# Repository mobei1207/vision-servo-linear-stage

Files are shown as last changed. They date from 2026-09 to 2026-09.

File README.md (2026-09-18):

# vision-servo-linear-stage

> 基于 STM32F103C8T6 与 Python/OpenCV 的视觉伺服直线运动平台，DM542 驱动 57 步进电机，串口通信实现视觉闭环自动对准。

[]()
[]()
[]()
[]()

---

## 项目简介

本项目为机械电子工程专业综合设计，开发一套基于视觉伺服控制的直线运动平台。系统采用上下位机主从控制架构：

- **上位机**：PC + Python + OpenCV，通过 USB 工业相机采集图像，识别红色目标，计算目标质心与画面中心的像素偏差，经串口发送运动指令。
- **下位机**：STM32F103C8T6，接收串口指令，输出 PWM 脉冲与方向信号，控制 DM542 驱动 57 步进电机，经 7:1 减速器带动 ECB80D 同步带模组，实现 500mm 行程内的直线运动。
- **闭环逻辑**：视觉检测 → 偏差计算 → 串口指令 → 电机运动 → 平台移动 → 视觉再检测，形成视觉闭环自动对准。

---

## 系统架构

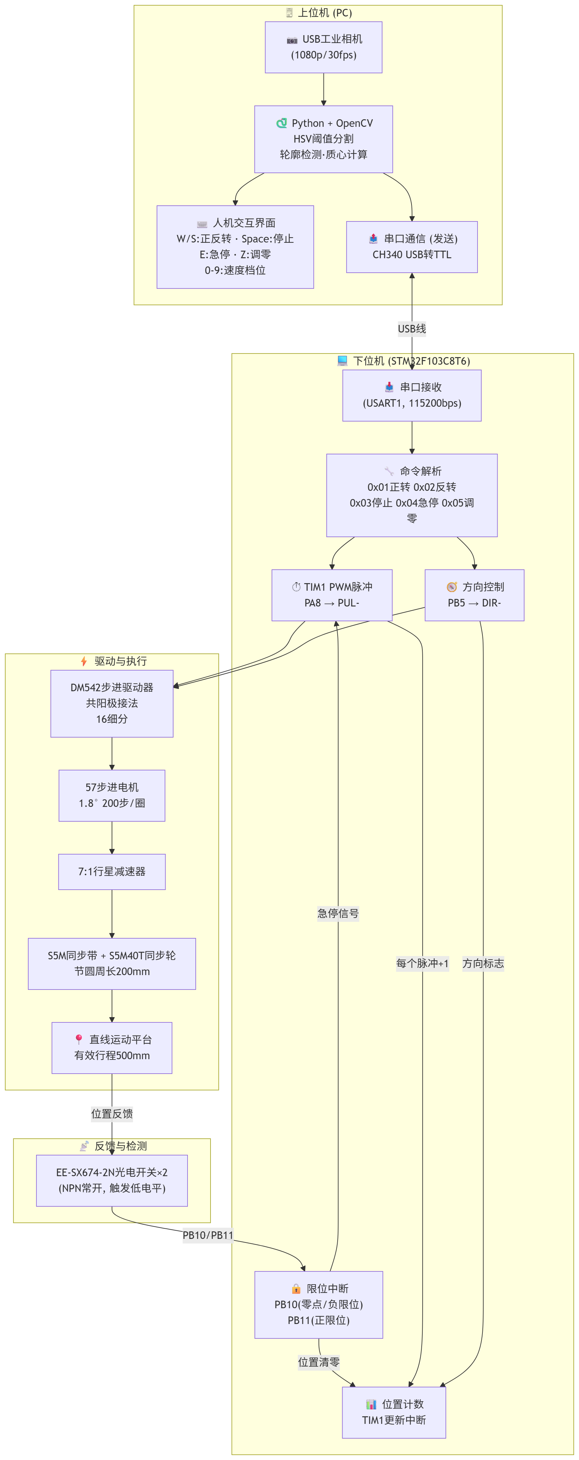
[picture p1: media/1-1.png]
系统结构图


---

## 硬件清单

| 类别 | 型号/规格 | 数量 | 说明 |
|---|---|---|---|
| 主控 | STM32F103C8T6 | 1 | 48 引脚 LQFP，72MHz |
| 驱动器 | DM542 | 1 | 两相步进驱动器，16 细分，共阳极接法 |
| 电机 | 57 两相混合式步进电机 | 1 | 机身 56mm，保持转矩约 1.2N·m，步距角 1.8° |
| 减速器 | 7:1 行星减速器 | 1 | 放大转矩，提高低速平稳性 |
| 模组 | ECB80D 欧规同步带模组 | 1 | 有效行程 500mm，重复定位精度 ±0.05mm |
| 同步轮 | S5M40T | 1 | 40 齿，节距 5mm，节圆周长 200mm |
| 同步带 | S5M 圆弧齿同步带 | 1 | 带宽 15mm |
| 相机 | USB 工业相机 | 1 | 1080p/30fps |
| 串口模块 | CH340 | 1 | USB 转 TTL，115200bps |
| 限位开关 | EE-SX674-2N | 2 | NPN 常开，负限位/零点 + 正限位 |
| 电源 | 24V 开关电源 | 1 | 驱动器主回路供电 |
| 电源 | DC-DC 5V 模块 | 1 | 光电开关、CH340 供电 |
| 电源 | 3.3V LDO | 1 | STM32 板载稳压 |
| 支架 | L 型相机支架 | 1 | PLA 3D 打印 |

---

## 软件环境

| 类别 | 工具/语言 | 说明 |
|---|---|---|
| 上位机 | Python 3.x | 主程序 |
| 视觉库 | OpenCV | 图像采集、HSV 分割、轮廓提取 |
| 串口库 | pyserial | 上下位机通信 |
| 下位机 | Keil MDK | STM32 程序开发 |
| 下位机库 | STM32 标准外设库 | GPIO、TIM、USART、中断 |
| 下位机语言 | C | 脉冲输出、方向控制、限位保护 |
| 电气设计 | Altium Designer / EPLAN | 电气接线图、供电拓扑图 |
| 机械设计 | SolidWorks | 模组装配、相机支架建模 |
| 下载工具 | FlyMcu | STM32 串口下载程序 |
| 调试工具 | SSCOM | 串口助手，发送十六进制指令 |

---

## 功能

- **初始化回零**：上电后电机以 3 档低速反转，触发负限位 PB10 后停止，位置变量清零。
- **手动点动**：W 正转，S 反转，空格停止，0~9 调节速度档位。
- **急停保护**：E 键急停，电机立即停止，再次按 E 解除。
- **限位安全保护**：PB10 负限位/零点，PB11 正限位，中断 + 主循环双重保护。
- **视觉识别**：HSV 颜色空间阈值分割，形态学滤波，轮廓提取，红色目标质心计算。
- **自动对准**：目标质心与画面中心偏差超过死区（15 像素）时，自动发送运动指令；空闲 1 秒后自动进入自动对准模式，速度固定 3 档。
- **串口通信**：4 字节固定帧，115200bps，帧头 0xAA，命令码 + 数据 + 校验和。
- **位置计数**：TIM1 更新中断中根据方向标志对位置变量递增或递减。

---

## 性能指标

| 指标 | 数值 | 说明 |
|---|---|---|
| 有效行程 | 500mm | ECB80D 模组 |
| 最高速度 | ≥5m/min | 满足任务书要求 |
| 最大加速度 | ≥1m/s² | 任务书要求 |
| 电机转速范围 | 15~200rpm | 10 档速度 |
| 同步轮节圆周长 | 200mm | 40 齿 × 5mm 节距 |
| 电机每转直线位移 | 28.57mm/rev | 200 ÷ 7 |
| 驱动器细分 | 16 | DM542 |
| 电机每圈脉冲数 | 3200 | 200 × 16 |
| 系统分辨率 | 0.00893mm/step | 28.57 ÷ 3200，优于 0.01mm/step |
| 重复定位精度 | ±0.05mm | ECB80D 模组 |
| 定位精度 | ±0.05mm | 满足 ±0.10mm 要求 |

---

## 目录结构

```
vision-servo-linear-stage/
├── README.md
├── code/
│   ├── upper_computer/              # 上位机 Python + OpenCV
│   │   ├── uhwzigxu0004.py          # 主程序
│   │   ├── requirements.txt         # Python 依赖
│   │   └── README.md
│   └── lower_computer/              # 下位机 STM32 Keil 工程
│       ├── Library/
│       ├── Hardware/
│       ├── User/
│       ├── System/
│       ├── Start/
│       ├── Project.uvoptx
│       ├── Project.uvprojx
│       └── README.md
├── hardware/
│   ├── Sheet10009.pdf               # 电气原理图
│   ├── 3-2.jpg                      # 共阳极接口电路
│   ├── 3-1 拷贝.png                 # 总体接线图 
│   └── IO分配表.md
├── mechanical/
│   ├── mechanical/0003-ECB80D-L200-S500-R-750W+减速机.STEP                 # SolidWorks 装配体与零件
│   ├── L型支架.STEP                                                        
│   ├── 相机.STEP
│   ├── 装配体6.STEP
│   └── 装配体6sw工程图.pdf                                                  # 工程图
├── docs/
│   ├── 设计说明书 - 副本.pdf
│   └── 通信协议.md
└── media/
    ├── demo.mp4                     # 演示视频（或网盘链接）
    ├── 1-1.png                      #系统结构图
    ├── 4-1.png                      #上位机流程图
    ├── 4-2.png                      #下位机流程图
    └── README.md
```

---

## 通信协议

上下位机采用固定 4 字节帧格式：

```
┌────────┬────────┬────────┬──────────┐
│  0xAA  │  CMD   │  DATA  │ CHECKSUM │
│  帧头  │  命令码 │ 数据   │   校验和  │
└────────┴────────┴────────┴──────────┘
```

- **帧头**：固定 `0xAA`
- **命令码**：见下表
- **数据**：速度档位 1~10，或 `0x00`
- **校验和**：`(0xAA + CMD + DATA) & 0xFF`

### 命令码定义

| CMD | 功能 | DATA | 说明 |
|-----|---|---|---|
| 0x01 | 正转 | 1~10 | 速度档位 |
| 0x02 | 反转 | 1~10 | 速度档位 |
| 0x03 | 停止 | 0x00 | 关闭 PWM |
| 0x04 | 急停 | 0x00 | 立即停止 |
| 0x05 | 调零 | 0x00 | 回零状态机 |

### 指令示例

| 功能 | 完整指令 (HEX) | 校验和 |
|---|---|---|
| 正转 1 档 | `AA 01 01 AC` | 0xAC |
| 正转 5 档 | `AA 01 05 B0` | 0xB0 |
| 正转 10 档 | `AA 01 0A B5` | 0xB5 |
| 反转 5 档 | `AA 02 05 B1` | 0xB1 |
| 停止 | `AA 03 00 AD` | 0xAD |
| 急停 | `AA 04 00 AE` | 0xAE |
| 调零 | `AA 05 00 AF` | 0xAF |

---

## STM32 引脚分配

| 引脚 | 功能 | 说明 |
|---|---|---|
| PA8 | TIM1_CH1 PWM 输出 | 脉冲信号，接 DM542 PUL- |
| PB5 | GPIO 输出 | 方向控制，低电平正转，高电平反转，接 DM542 DIR- |
| PB10 | GPIO 输入（上拉） | 负限位/零点光电开关，低电平触发 |
| PB11 | GPIO 输入（上拉） | 正限位光电开关，低电平触发 |
| PA9 | USART1_TX | 串口发送，备用调试 |
| PA10 | USART1_RX | 串口接收，接 CH340 TX |
| PA13 | SWDIO | 程序下载与调试 |
| PA14 | SWCLK | 程序下载与调试 |
| VDD/VSS | 电源 | 3.3V 供电与接地 |

### DM542 接线表

| DM542 端子 | 接到 | 说明 |
|---|---|---|
| PUL+ | +5V | 共阳极 |
| PUL- | PA8 | 脉冲 |
| DIR+ | +5V | 共阳极 |
| DIR- | PB5 | 方向 |
| ENA+ | 悬空 | 不使能 |
| ENA- | 悬空 | 不使能 |
| VCC | +24V | 主电源 |
| GND | 24V GND | 地 |
| A+ / A- / B+ / B- | 57 步进电机 | 两相四线 |

---

## 调试记录

### 调试工具

- **FlyMcu**：STM32 串口下载程序
- **SSCOM**：串口助手，发送十六进制指令，验证上下位机通信
- **万用表**：测量 24V、5V、3.3V 供电
- **示波器**：测量 PA8 PWM 波形

### 调试步骤

1. **下位机独立调试**：用 SSCOM 发送 `AA 05 00 AF` 调零，`AA 01 05 B0` 正转，`AA 02 05 B1` 反转，`AA 03 00 AD` 停止，`AA 04 00 AE` 急停。
2. **上位机独立调试**：运行 Python 程序，用红色物体测试 HSV 识别与质心标记。
3. **联调**：上下位机同时上电，测试手动、自动、急停、限位。

### 问题与解决

| 序号 | 问题 | 原因 | 解决 |
|---|---|---|---|
| 1 | 电机不转，驱动器无反应 | PUL+ 与 DIR+ 并联接 +5V 处虚焊 | 重新焊接 |
| 2 | 电机方向与预期相反 | 方向逻辑反相 | 交换电机 A+ 与 A- |
| 3 | 调零完成后电机仍然缓慢转动 | `PWM_Stop()` 未关闭 `TIM_CtrlPWMOutputs` | 补充关闭主输出 |
| 4 | 自动对准方向与期望相反 | 上位机 `dx > 0` 时错误发送正转 | 修正为 `dx > 0` 发反转 |
| 5 | 手动按键控制被自动模式频繁打断 | 手动按键后未重置空闲计时器 | 手动分支重置计时器 |
| 6 | 急停后状态混乱，无法恢复正常控制 | 解除急停时未重置状态标志位 | 重置 `last_stop_sent`、`mode`、`manual_stopped` |
| 7 | 自动对准时电机频繁启停，产生异响 | 每帧都发送指令，方向频繁切换 | 记录上次方向，调用频率降至 10Hz |
| 8 | 红色阈值在自然光照变化时识别不稳定 | HSV 阈值受光照影响 | 形态学滤波 + 缩小阈值 + 室内遮光 |

---

## 运行说明

### 上位机

```bash
cd code/upper_computer
pip install -r requirements.txt
python main.py
```

**操作说明：**

| 按键 | 功能 |
|---|---|
| W | 正转 |
| S | 反转 |
| 空格 | 停止 |
| E | 急停/解除急停 |
| Z | 调零 |
| 0~9 | 速度档位 |
| Q | 退出 |

空闲 1 秒后自动进入自动对准模式，速度固定 3 档。

### 下位机

1. 用 Keil MDK 打开 `code/lower_computer/` 下的工程文件。
2. 编译生成 `.hex` 文件。
3. 用 FlyMcu 通过串口下载到 STM32F103C8T6。
4. 上电后自动进入回零状态，等待上位机指令。

### 串口调试

用 SSCOM 发送十六进制指令：

```
AA 05 00 AF    # 调零
AA 01 05 B0    # 正转 5 档
AA 02 05 B1    # 反转 5 档
AA 03 00 AD    # 停止
AA 04 00 AE    # 急停
```

---

## 本人负责

- 独立完成上下位机程序开发与联调。
- 完成 STM32 引脚分配、PWM 脉冲输出、方向控制、限位保护、位置计数。
- 完成 Python + OpenCV 视觉识别、串口通信、手动/自动模式切换。
- 参与机械装配、电气接线、系统调试与问题排查。
- 编写设计说明书、通信协议、IO 分配表、调试记录。

---

## 不足与改进方向

1. **开环驱动**：未配备编码器，位置反馈仅靠脉冲计数，无法补偿皮带弹性变形和机械间隙。后续可增加 E6B2 编码器，构成全闭环位置控制，引入 PI 调节。
2. **视觉识别鲁棒性**：基于 HSV 阈值分割，对环境光照变化敏感。后续可引入 YOLO 等深度学习目标检测算法。
3. **通信带宽**：串口速率有限，限制视觉反馈周期。后续可采用 USB 虚拟串口或以太网。
4. **机械精度**：同步带传动存在弹性变形，高速时可能跳齿。后续可优化张紧机构或改用滚珠丝杠。

---

## 参考资料

1. 周俊宇，夏琳燕，周全，黄俊. 基于运动控制卡和工业视觉的综合实训平台设计[J]. 长沙大学学报，2021，35(5)：29-33.
2. 解彬彬，孟鑫朋，曹洪玮，等. 农业采摘机器人视觉-伺服抓取实验平台设计与教学应用[J]. 新疆农机化，2026(3)：53-61.
3. 黄建军，邵中魁，陶仁和，姜耀林. 基于单片机的位置实时精调伺服控制系统开发[J]. 精密制造与自动化，2021(3)：18-22.
4. 马福阳，申迎风，蒋博，等. 基于STM32F103C8T6的YOLOV5目标检测与喷涂控制系统设计[J]. 电子技术，2026，55(2)：876-877.
5. 王焕云，李慨. 基于网络直角坐标机器人视觉伺服控制系统理论研究[J]. 沧州师范专科学校学报，2005，21(4)：85-88.
6. 杨军莉. 基于工业机器人视觉伺服控制系统研究[J]. 自动化技术与应用，2020，39(8)：66-69.

---

## 作者

- 郭司南
- 内蒙古工业大学 机械工程学院 机械电子工程

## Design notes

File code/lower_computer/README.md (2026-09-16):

# 下位机程序说明（STM32F103C8T6）

本程序为视觉伺服直线运动平台的下位机部分，运行于 STM32F103C8T6 单片机。主要功能包括：接收上位机通过串口发送的运动指令，解析指令并控制步进电机正转、反转、停止、急停、回零，输出 PWM 脉冲与方向信号驱动 DM542 控制 57 步进电机，读取限位开关状态实现限位保护与回零，并通过定时器中断进行位置计数。

---

## 开发环境

| 项目 | 说明 |
|---|---|
| 芯片 | STM32F103C8T6（48 引脚 LQFP，72MHz） |
| 开发工具 | Keil MDK 5 |
| 固件库 | STM32 标准外设库（StdPeriph Lib） |
| 下载工具 | FlyMcu（串口下载）或 ST-Link |
| 调试工具 | SSCOM 串口助手、万用表、示波器 |

---

## 目录结构

```
lower_computer/
├── User/                   # 用户代码
│   ├── main.c              # 主函数：初始化 + 主循环
│   ├── stm32f10x_it.c      # 中断服务函数
│   └── stm32f10x_it.h
├── Hardware/               # 硬件驱动
│   ├── motor.c / motor.h   # 电机控制：PWM、方向、启停
│   ├── limit.c / limit.h   # 限位开关读取
│   ├── serial.c / serial.h # 串口通信与命令解析
│   ├── timer.c / timer.h   # TIM1 PWM 配置与更新中断
│   └── delay.c / delay.h   # 延时函数
├── Library/                # STM32 标准外设库
├── Start/                  # 启动文件
├── System/                 # 系统文件
└── Project/                # Keil 工程文件
    ├── Project.uvprojx
    └── Project.uvoptx
```

如果你的工程目录不同，请按实际结构调整。

---

## 编译与下载

用 Keil MDK 5 打开 `Project/Project.uvprojx`，点击 Build 编译工程，确认无错误后生成 `.hex` 文件（默认在 `Objects/` 目录下）。然后使用 FlyMcu 通过串口下载：选择正确串口（CH340 对应的 COM 口），波特率一般选 115200，加载 `.hex` 文件，点击“开始编程”。下载完成后给 STM32 重新上电，程序开始运行。也可使用 ST-Link 通过 SWD 接口下载调试。

---

## 引脚分配

| 引脚 | 功能 | 说明 |
|---|---|---|
| PA8 | TIM1_CH1 PWM 输出 | 脉冲信号，接 DM542 的 PUL- |
| PB5 | GPIO 输出 | 方向控制，低电平正转，高电平反转，接 DM542 的 DIR- |
| PB10 | GPIO 输入（上拉） | 负限位/零点光电开关，低电平触发 |
| PB11 | GPIO 输入（上拉） | 正限位光电开关，低电平触发 |
| PA9 | USART1_TX | 串口发送（备用调试） |
| PA10 | USART1_RX | 串口接收，接 CH340 的 TX |
| PA13 | SWDIO | 程序下载与调试 |
| PA14 | SWCLK | 程序下载与调试 |
| VDD/VSS | 电源 | 3.3V 供电与接地 |

### DM542 接线

| DM542 端子 | 接到 | 说明 |
|---|---|---|
| PUL+ | +5V | 共阳极 |
| PUL- | PA8 | 脉冲 |
| DIR+ | +5V | 共阳极 |
| DIR- | PB5 | 方向 |
| ENA+ / ENA- | 悬空 | 不使能 |
| VCC | +24V | 主电源 |
| GND | 24V GND | 地 |
| A+ / A- / B+ / B- | 57 步进电机 | 两相四线 |

---

## 功能说明

### 1. 初始化回零

上电后程序自动进入回零状态：电机以 3 档低速反转，直到 PB10 检测到负限位触发，电机停止并将位置变量清零。

### 2. 手动控制

通过串口接收上位机指令：

| 命令码 | 功能 | 数据 |
|---|---|---|
| 0x01 | 正转 | 速度档位 1~10 |
| 0x02 | 反转 | 速度档位 1~10 |
| 0x03 | 停止 | 0x00 |
| 0x04 | 急停 | 0x00 |
| 0x05 | 调零 | 0x00 |

### 3. 限位保护

主循环中定时读取 PB10 和 PB11 电平，当限位触发时立即停止电机，防止超出行程。同时支持外部中断方式，具体见实际代码。

### 4. 位置计数

TIM1 更新中断中，每产生一个脉冲，根据方向标志对位置变量递增或递减，用于调试参考。

### 5. 速度档位

通过查表方式设置 TIM1 的 ARR 值，实现 10 档速度，对应电机转速约 15~200rpm。

---

## 串口通信协议

上下位机采用固定 4 字节帧格式：

```
AA + CMD + DATA + CHECKSUM
```

其中 AA 为帧头，CMD 为命令码，DATA 为数据（速度档位或 0x00），CHECKSUM 为 `(AA + CMD + DATA) & 0xFF`。

| CMD | 功能 | DATA |
|-----|---|---|
| 0x01 | 正转 | 1~10 |
| 0x02 | 反转 | 1~10 |
| 0x03 | 停止 | 0x00 |
| 0x04 | 急停 | 0x00 |
| 0x05 | 调零 | 0x00 |

指令示例：

| 功能 | 指令 (HEX) |
|---|---|
| 正转 5 档 | `AA 01 05 B0` |
| 反转 5 档 | `AA 02 05 B1` |
| 停止 | `AA 03 00 AD` |
| 急停 | `AA 04 00 AE` |
| 调零 | `AA 05 00 AF` |

---

## 调试说明

### 下位机独立调试

使用 SSCOM 串口助手，波特率 115200，十六进制发送。先发送调零指令 `AA 05 00 AF`，观察电机是否向负限位方向运动并停止。然后发送正转 `AA 01 05 B0`、反转 `AA 02 05 B1`、停止 `AA 03 00 AD`、急停 `AA 04 00 AE`，验证功能。用手遮挡限位开关，电机应立即停止。串口助手可接收到 STM32 打印的调试信息，如 `Forward, speed level: 5`。

### 常见问题

| 现象 | 可能原因 | 解决方法 |
|---|---|---|
| 电机不转 | 接线松动、PUL+ 未接 +5V | 检查接线，确认共阳极 |
| 方向相反 | 电机相序接反 | 交换 A+ 与 A- |
| 调零后电机缓转 | PWM_Stop 未关主输出 | 在 PWM_Stop 中调用 `TIM_CtrlPWMOutputs(TIM1, DISABLE)` |
| 限位不触发 | 光电开关供电或接线问题 | 检查 5V 供电与信号线 |
| 串口无响应 | 波特率或串口线接错 | 确认 115200，TX/RX 交叉连接 |

---
## 流程图

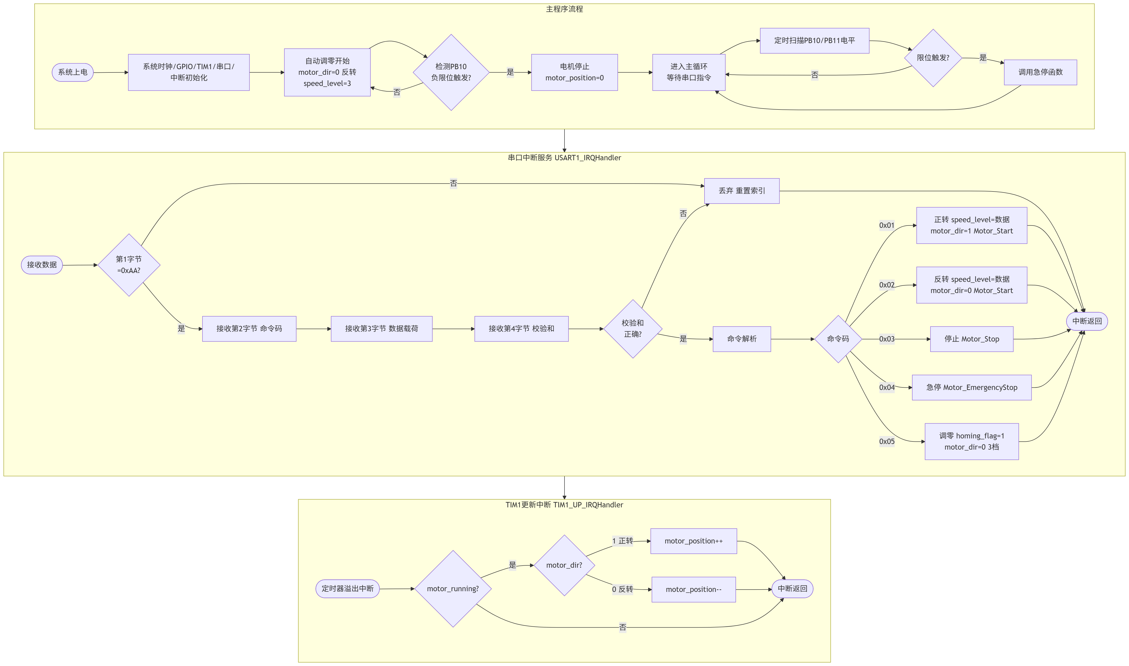
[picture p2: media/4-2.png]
程序流程图


---

## 备注

本程序为课程设计版本，采用 STM32 标准外设库开发。如需修改速度档位或加减速参数，可在 `timer.c` 中调整 ARR 查表值。位置计数变量在 `motor.c` 中定义，可通过串口打印观察。程序未使用编码器，为开环控制，后续可增加编码器实现闭环。

---

## 作者

- 郭司南
- 内蒙古工业大学 机械工程学院 机械电子工程

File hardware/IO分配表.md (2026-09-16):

# IO 分配表

本文档记录视觉伺服直线运动平台的电气 IO 分配、接线关系与供电方案。

---

## 1. STM32F103C8T6 引脚分配

| 引脚 | 功能 | 方向 | 说明 |
|---|---|---|---|
| PA8 | TIM1_CH1 PWM 输出 | 输出 | 脉冲信号，接 DM542 的 PUL- |
| PB5 | GPIO 输出 | 输出 | 方向控制，低电平正转，高电平反转，接 DM542 的 DIR- |
| PB10 | GPIO 输入（上拉） | 输入 | 负限位/零点光电开关，低电平触发 |
| PB11 | GPIO 输入（上拉） | 输入 | 正限位光电开关，低电平触发 |
| PA9 | USART1_TX | 输出 | 串口发送，备用调试 |
| PA10 | USART1_RX | 输入 | 串口接收，接 CH340 的 TX |
| PA13 | SWDIO | 双向 | 程序下载与调试 |
| PA14 | SWCLK | 输入 | 程序下载与调试 |
| VDD | 电源 | — | 3.3V 供电 |
| VSS | 电源 | — | 接地 |

---

## 2. DM542 驱动器接线

| DM542 端子 | 接到 | 说明 |
|---|---|---|
| PUL+ | +5V | 共阳极接法 |
| PUL- | PA8 | 脉冲信号 |
| DIR+ | +5V | 共阳极接法 |
| DIR- | PB5 | 方向信号 |
| ENA+ | 悬空 | 不使能 |
| ENA- | 悬空 | 不使能 |
| VCC | +24V | 主电源正极 |
| GND | 24V GND | 主电源负极 |
| A+ | 57 步进电机 A+ | 电机 A 相 |
| A- | 57 步进电机 A- | 电机 A 相 |
| B+ | 57 步进电机 B+ | 电机 B 相 |
| B- | 57 步进电机 B- | 电机 B 相 |

**细分设置：** DM542 拨码 SW1~SW4 设置为 16 细分（具体拨码见驱动器面板表）。

---

## 3. 限位开关接线

| 光电开关 | 端子 | 接到 | 说明 |
|---|---|---|---|
| 负限位/零点（左端） | VCC | +5V | 供电 |
| 负限位/零点（左端） | GND | GND | 地 |
| 负限位/零点（左端） | OUT | PB10 | 低电平触发 |
| 正限位（右端） | VCC | +5V | 供电 |
| 正限位（右端） | GND | GND | 地 |
| 正限位（右端） | OUT | PB11 | 低电平触发 |

**型号：** EE-SX674-2N，NPN 常开型。

---

## 4. CH340 串口模块接线

| CH340 端子 | 接到 | 说明 |
|---|---|---|
| TX | PA10（USART1_RX） | 交叉连接 |
| RX | PA9（USART1_TX） | 交叉连接 |
| VCC | 3.3V 或 5V | 与 STM32 逻辑电平匹配，建议 3.3V |
| GND | GND | 共地 |

**通信参数：** 波特率 115200，数据位 8，停止位 1，无校验。

---

## 5. 供电分配

| 电源 | 电压 | 供给对象 | 说明 |
|---|---|---|---|
| 220V 交流市电 | AC 220V | 24V 开关电源 | 输入 |
| 24V 开关电源 | DC 24V | DM542 驱动器主回路 | 电机驱动 |
| DC-DC 降压模块 | DC 5V | 光电开关、CH340 | 由 24V 降压 |
| STM32 板载 LDO | DC 3.3V | STM32 芯片及外围 | 由 5V 稳压 |

**共地要求：** 24V、5V、3.3V 的 GND 必须单点共地，确保信号参考电位一致。

---

## 6. 电气接线注意事项

1. 强弱电分离：24V 驱动回路使用 0.75mm² 导线，控制信号线使用 0.15mm² 导线，分开走线。
2. 信号线采用屏蔽线，屏蔽层单端接地。
3. 驱动器主回路与控制回路之间通过光耦隔离。
4. 接线端子采用插拔式接线排，便于调试更换。
5. 全部接线完成后，先进行对地绝缘测试和短路测试，确认无误后再通电。
6. 通电后先测量各电压节点：DM542 的 VCC 与 GND 应为 24V，STM32 的 3.3V 和 5V 应正常。

---

## 7. 接线总览

```
上位机 PC
  ├── USB 工业相机
  └── CH340 模块
        ├── TX → PA10
        ├── RX → PA9
        ├── VCC → 3.3V
        └── GND → GND

STM32F103C8T6
  ├── PA8 → DM542 PUL-
  ├── PB5 → DM542 DIR-
  ├── PB10 → 负限位/零点光电开关 OUT
  ├── PB11 → 正限位光电开关 OUT
  ├── PA13 → SWDIO
  ├── PA14 → SWCLK
  ├── VDD → 3.3V
  └── VSS → GND

DM542
  ├── PUL+ → +5V
  ├── PUL- → PA8
  ├── DIR+ → +5V
  ├── DIR- → PB5
  ├── VCC → +24V
  ├── GND → 24V GND
  └── A+/A-/B+/B- → 57 步进电机

供电
  ├── 220V AC → 24V 开关电源 → DM542
  ├── 24V → DC-DC 5V → 光电开关、CH340
  └── 5V → 3.3V LDO → STM32
```

---

## 8. 备注

- 本表对应课程设计《视觉伺服直线运动平台》。
- 实际接线以电气接线图为准。
- 若更换驱动器或电机型号，需重新核对引脚定义与供电电压。

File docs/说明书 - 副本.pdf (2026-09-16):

摘要

本设计针对机电一体化教学需求，开发了一套基于视觉伺服控制的直线运动平 台。该平台采用上下位主从控制架构，以欧规同步带模组（ECB80D）为执行机构，

以 57 步进电机配合 7:1 减速器为动力单元，由 DM542 数字式步进驱动器驱动；下位

机选用 STM32F103C8T6 单片机，负责脉冲输出、方向控制、限位检测与位置计数；

## 上位机基于 Python 与 OpenCV 开发视觉识别程序，通过 USB 工业相机（1080p/30fps）

采集图像，采用 HSV 颜色阈值分割与轮廓检测算法识别红色目标，计算目标质心与

画面中心的像素偏差，经 CH340 模块以串口通信方式向下位机发送运动指令，形成

视觉闭环。平台有效行程 500mm，同步轮节圆周长 200mm，经 7:1 减速后电机每转

## 对应直线位移约 28.57mm，配合 DM542 的 16 细分设置，分辨率可达 0.00893mm/step，

优于任务书要求的 0.01mm/step。系统实现了初始化回零、手动点动控制、空闲自动

对准及限位安全保护等功能。本文详细阐述了方案论证、结构计算、电控系统设计、

上下位机程序开发、装配调试过程及设计总结，为机电一体化专业综合设计提供了一

套完整的工程实践案例。

关键词：视觉伺服；同步带模组；STM32；步进电机；OpenCV；串口通信

目录

摘要 | I

第一章

## 第一章 方案论证

## 1.1 设计任务与总体目标

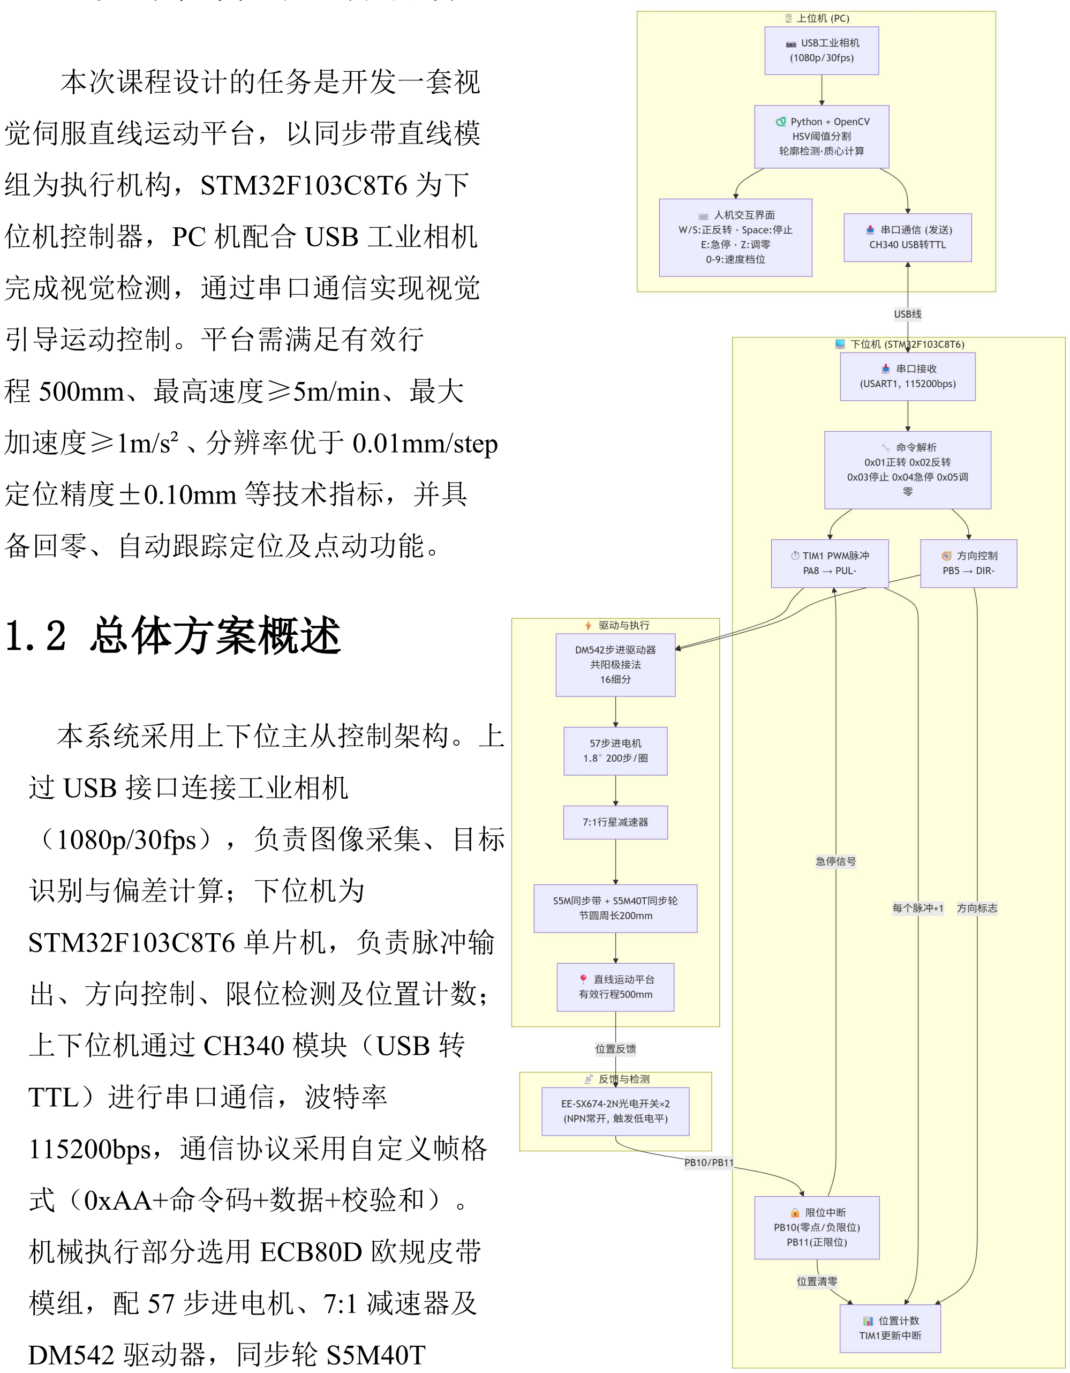
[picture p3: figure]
加速度≥1m/s²、分辨率优于 0.01mm/step; 定位精度±0.10mm 等技术指标，并具; 备回零、自动跟踪定位及点动功能。; 1.2 总体方案概述; 本系统采用上下位主从控制架构。上; 位机为 PC 机，通; 过 USB 接口连接工业相机; （1080p/30fps），负责图像采集、目标; 识别与偏差计算；下位机为 STM32F103C8T6 单片机，负责脉冲输; 出、方向控制、限位检测及位置计数；; 上下位机通过 CH340 模块（USB 转; TTL）进行串口通信，波特率; 115200bps，通信协议采用自定义帧格; 式（0xAA+命令码+数据+校验和）。; 机械执行部分选用 ECB80D 欧规皮带; 模组，配 57 步进电机、7:1 减速器及 DM542 驱动器，同步轮 S5M40T

本次课程设计的任务是开发一套视

觉伺服直线运动平台，以同步带直线模

## 组为执行机构，STM32F103C8T6 为下

位机控制器，PC 机配合 USB 工业相机

完成视觉检测，通过串口通信实现视觉

引导运动控制。平台需满足有效行

## 程 500mm、最高速度≥5m/min、最大

（40 齿，节距 5mm），有效行程 500mm[1]。 | 图 1-1 系统总体结构框图

第一章

该方案将计算密集的视觉处理交由上位机，实时性要求高的脉冲输出与限位响应 交由单片机，分工合理；上下位机相对独立，便于分阶段调试[2]。

## 1.3 机械传动方案论证

1.3.1 传动形式选择

滚珠丝杠传动精度高、刚性好，适用于重载高精度场景，但成本高、长行程易产

生累积误差；同步带传动结构简单、成本低、安装方便、运行噪声小，适于高速往复 运动[1]。任务书要求最高速度≥5m/min、加速度≥1m/s²，载荷≤3kg，同步带完全满

足。依据学号末位为偶数的要求，选用同步带传动方案。

## 1.3.2 模组选型

选用 ECB80D 欧规皮带模组，配套 S5M 型圆弧齿同步带（带宽 15mm）及 S5M40T

同步轮（40 齿，节距 5mm），重复定位精度±0.05mm，满足±0.10mm 要求。模组

两端安装光电开关（EE-SX674-2N，NPN 常开）用于回零和限位保护，直线导轨导

向确保运行平稳。

1.3.3 驱动与减速方案

57 步进电机（机身 56mm，保持转矩约 1.2N·m）经 7:1 减速器驱动同步带轮，

减速器一方面放大转矩，另一方面使电机运行于较高转速区避开低速共振，提高低速 平稳性。DM542 驱动器采用共阳极接法、16 细分设置，分辨率约 0.00893mm/step，

优于指标要求[3]。

## 1.4 电控系统方案论证

## 1.4.1 控制器选型

PLC 可靠性高但扩展脉冲输出需额外模块且与上位机交互灵活性差；

STM32F103C8T6 成本低、资源丰富、定时器可产生 PWM 脉冲、串口通信便捷，主

## 频 72MHz 保证实时性[4]。选用 STM32F103C8T6 为下位机控制器。

1.4.2 脉冲发生与限位保护

第一章

## TIM1 配置为 PWM 输出模式产生脉冲（PA8 输出至 DM542 的 PUL-），PB5 控

制方向（DIR-）。脉冲频率通过查表方式切换 10 档速度（15~200rpm 对应电机转速）。

限位检测采用 PB10（零点/负限位）和 PB11（正限位），外部中断结合主循环扫描

实现双重保护[5]。

## 1.4.3 位置计数

TIM1 更新中断中根据方向标志对位置变量递增或递减，实时记录平台相对原点

的脉冲数，作为调试辅助和状态参考。

## 1.5 视觉检测方案论证

## 上位机基于 Python 和 OpenCV 开发，利用 pyserial 实现串口通信[2]。采用 HSV

颜色空间阈值分割识别红色目标，结合形态学滤波和轮廓提取获得质心坐标，相比深

度学习方法计算量小、实时性好、无需训练数据。

控制策略：计算目标质心与画面中心的水平偏差 dx，|dx|超过死区（15 像素）时

发送运动指令，进入死区则停止。设置手动和自动两种模式：手动操作停止且空闲超 1 秒后自动切换至自动对准模式（速度固定 3 档），避免振荡[6]。

## 1.6 方案总结

本方案采用“上位机 PC+下位机 STM32”主从结构，以同步带模组为执行机构，

USB 工业相机为视觉传感器，DM542 驱动 57 步进电机实现平台运动。系统分工合理，

满足技术参数要求，兼顾成本与可扩展性，方案可行。

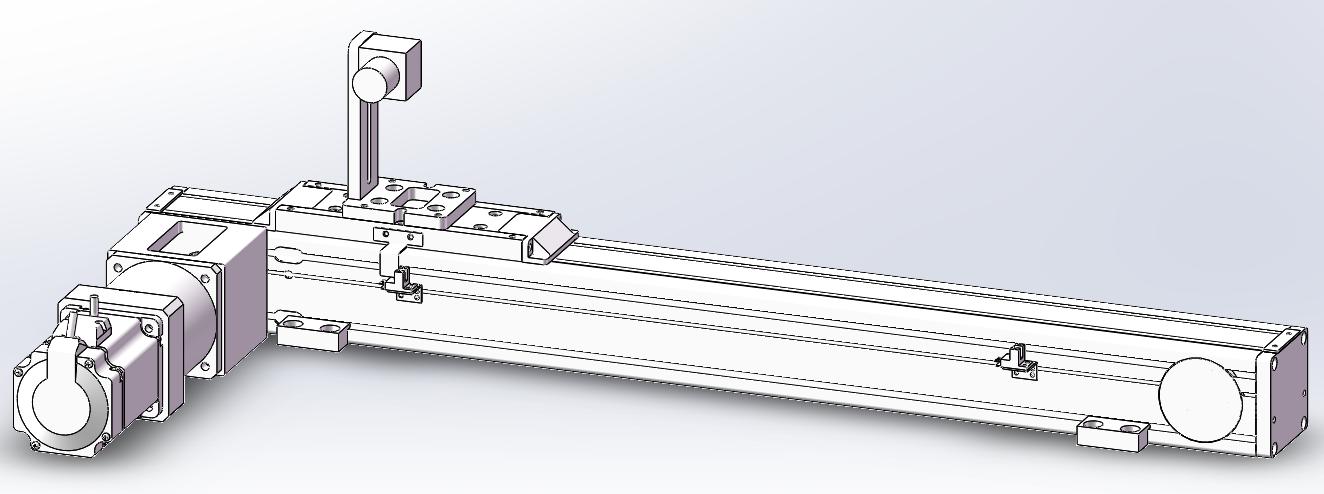
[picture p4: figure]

图 1-2 总体装配模型

第二章

## 第二章 结构计算

## 2.1 同步带传动参数计算

本系统采用 S5M 型圆弧齿同步带传动，同步轮齿数为 40 齿，节距为 5mm。同

步轮的节圆周长即为电机经减速器后每旋转一圈所驱动的直线位移量，计算如下：

## 同步轮节圆周长 C = 40 × 5 = 200mm

（2-1）

由于电机与同步轮之间安装了 7:1 的行星减速器，电机轴旋转 7 圈时减速器输出

轴旋转 1 圈，即同步轮旋转 1 圈。因此，电机每旋转一圈对应的平台直线位移为：

## 电机每转直线位移 = 200 ÷ 7 ≈ 28.57mm/rev

（2-2）

ECB80D 模组的有效行程为 500mm，对应同步轮需旋转 2.5 圈，电机需旋转 17.5

圈。

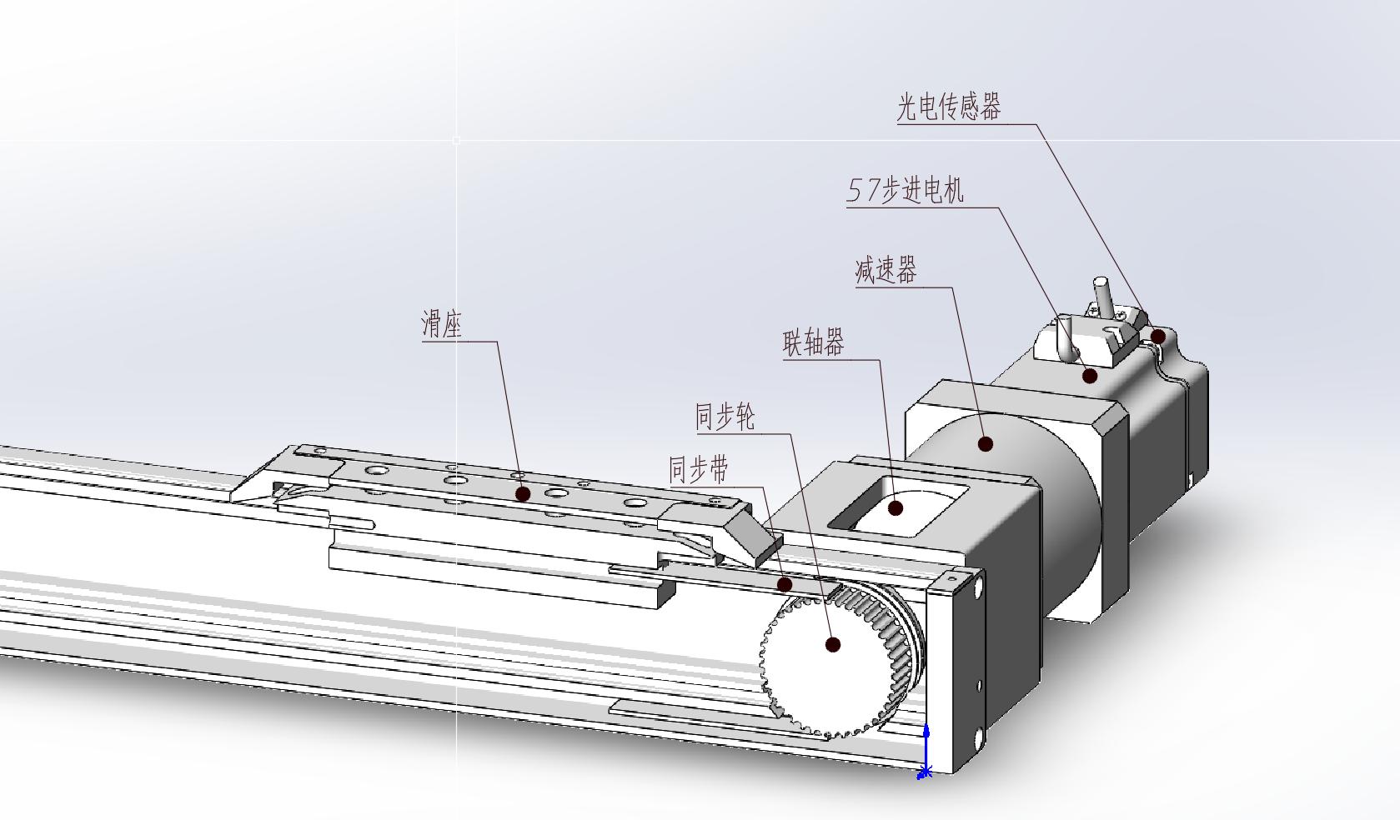
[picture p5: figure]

图 2-1 传动链结构示意图

第二章

## 2.2 步进电机选型

步进电机的选型需同时满足速度要求、转矩要求和惯量匹配要求，三者缺一不可。

## 2.2.1 转速需求

任务书要求最高运行速度不小于 5m/min（即 5000mm/min）。由等效导程 28.57mm

可得，达到最高速度所需电机转速为：

n = 5000 ÷ 28.57 ≈ 175rpm | （2-3）

步进电机的常用工作转速范围为 0~600rpm，在 175rpm 时多数 57 系列步进电机

仍处于额定转矩区间，速度需求容易满足。考虑到实际运行时需留有一定余量，将最 高转速目标设为 200rpm。

## 2.2.2 转矩需求

ECB80D 模组滑座质量约为 2.5kg，负载质量不超过 3kg，总运动质量 m ≈

5.5kg。任务书要求最大加速度 a = 1m/s²，则加速所需驱动力为：

F = m × a = 5.5 × 1 = 5.5N | （2-4）

## 同步轮半径 r = C / (2π) = 200 / 6.28 ≈ 31.83mm = 0.03183m，则加速所需驱动

转矩为：

T = F × r = 5.5 × 0.03183 ≈ 0.175N·m | （2-5）

经 7:1 减速器放大后，电机所需输出转矩为：

| （2-6）

考虑到同步带传动效率（约 90%~95%）、摩擦阻力及启动时的冲击载荷，取 1.5

倍安全系数：

| （2-7）

第二章

57 步进电机的保持转矩通常为 0.5~1.2N·m（机身越长转矩越大），即使在高速

运转时转矩有所下降，仍远大于 0.038N·m 的需求，转矩裕量极为充足。

## 2.2.3 惯量匹配

步进电机选型中，负载惯量与电机转子惯量之比应控制在合理范围内（通常建议 ≤10）。负载折算至电机轴的等效转动惯量为：

（2-8）

## 其中 P = 0.02857m，代入得：

（2-9）

57 步进电机转子惯量典型值约为 3.0×10⁻ ⁵ kg·m²（随具体型号略有差异），

惯量比为：

（2-10）

该值远优于 10:1 的上限要求，系统动态响应性能良好[5]。

## 2.2.4 选型结论

综合转速、转矩和惯量三方面计算，选用 57 系列两相混合式步进电机，机身长

度为 56mm。该型号保持转矩约 1.2N·m，转子惯量约 3.0×10⁻ ⁵ kg·m²，在 200rpm

时输出转矩仍有足够裕量，完全满足本系统的驱动需求。电机驱动器选用 DM542 并

设置 16 细分，配套 7:1 行星减速器使用。

## 2.3 分辨率与精度校核

2.3.1 步进驱动分辨率

57 步进电机的步距角为 1.8°，即电机每接收 200 个脉冲旋转一圈。DM542 驱动

器设置为 16 细分，则电机旋转一圈所需的脉冲数为：

电机每圈脉冲数 = 200 × 16 = 3200 脉冲/圈 | （2-11）

第二章

结合等效导程 28.57mm，系统理论分辨率为：

分辨率 = 28.57 ÷ 3200 ≈ 0.00893mm/step | （2-12）

该值优于任务书要求的 0.01mm/step，满足设计指标[3]。

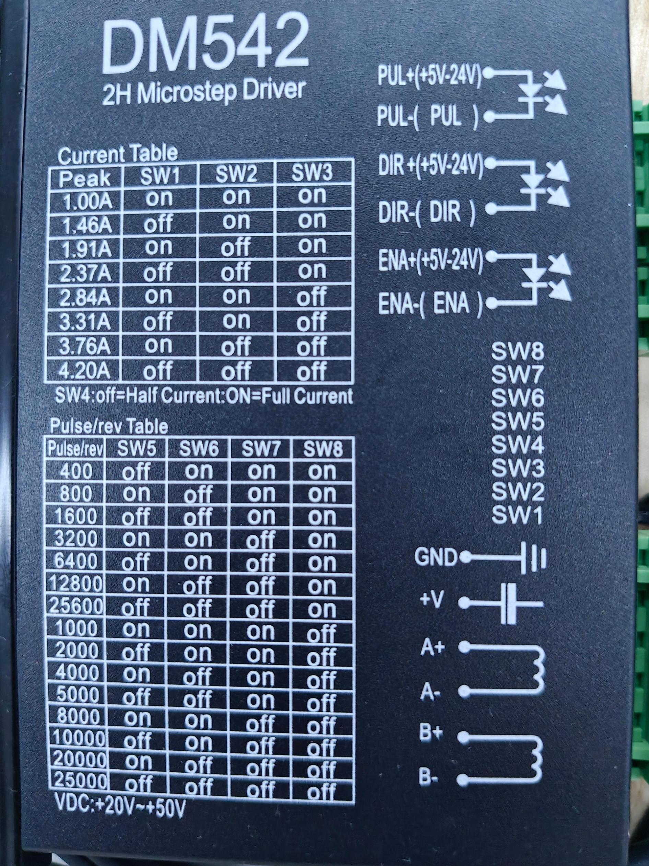
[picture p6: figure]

## 图 2-1 DM542 驱动器细分表

2.3.2 定位精度分析

ECB80D 模组的重复定位精度为±0.05mm。DM542 驱动器的细分误差和 57 步进

电机的步距角误差通常在±3%~±5%之间，折算到直线位移约为±0.0009mm，相对

机械精度而言可以忽略。系统定位精度主要取决于模组本身的机械精度，留有裕量后 仍可满足±0.10mm 的任务书要求[1][3]。

## 2.4 限位开关安装位置设计

负限位兼零点光电开关（EE-SX674-2N，NPN 常开）安装于模组左端，安装位

置应保证滑块在触及开关时与端盖之间留有约 2~3mm 的机械余量。正限位光电开关

对称安装于右端。负限位作为回零基准，其安装位置的重复性直接影响原点精度，

第二章

EE-SX674-2N 的检测精度可达 0.01mm 级，足以满足要求。光电开关输出信号经上拉

## 电阻接入 STM32 的 PB10 和 PB11 引脚。

## 2.5 本章小结

本章完成了同步带传动系统的核心参数计算与电机选型。同步轮节圆周长 200mm，经 7:1 减速后电机每转对应直线位移 28.57mm；根据速度、转矩和惯量三方

面需求，选用 57 步进电机（机身 56mm），在 200rpm 时仍保持充足转矩裕量，惯量

比约 3.8，动态响应良好；配合 16 细分设置，系统分辨率达 0.00893mm/step，优于指

标要求；定位精度约±0.05mm，满足±0.10mm 的要求。本章计算结果表明所选方案

满足全部性能指标要求[1][3][5]。

第四章

## 第三章 电控设计

## 3.1 硬件总体架构

本系统电控部分以上位机 PC 与下位机 STM32F103C8T6 为核心，外围硬件包括

## USB 工业相机、CH340 串口模块、DM542 步进驱动器、57 步进电机及 EE-SX674-2N

光电开关。上位机通过 USB 接口连接相机采集图像，通过另一 USB 口连接 CH340

模块实现与 STM32 的串口通信。下位机 STM32 负责解析串口指令、产生 PWM 脉冲

控制步进电机、读取限位开关状态并执行安全保护逻辑。全部控制信号为低压直流信 号，驱动器主回路采用 24V 直流供电，与控制回路电气隔离。图 3-1 为电控系统硬件

连接关系图。

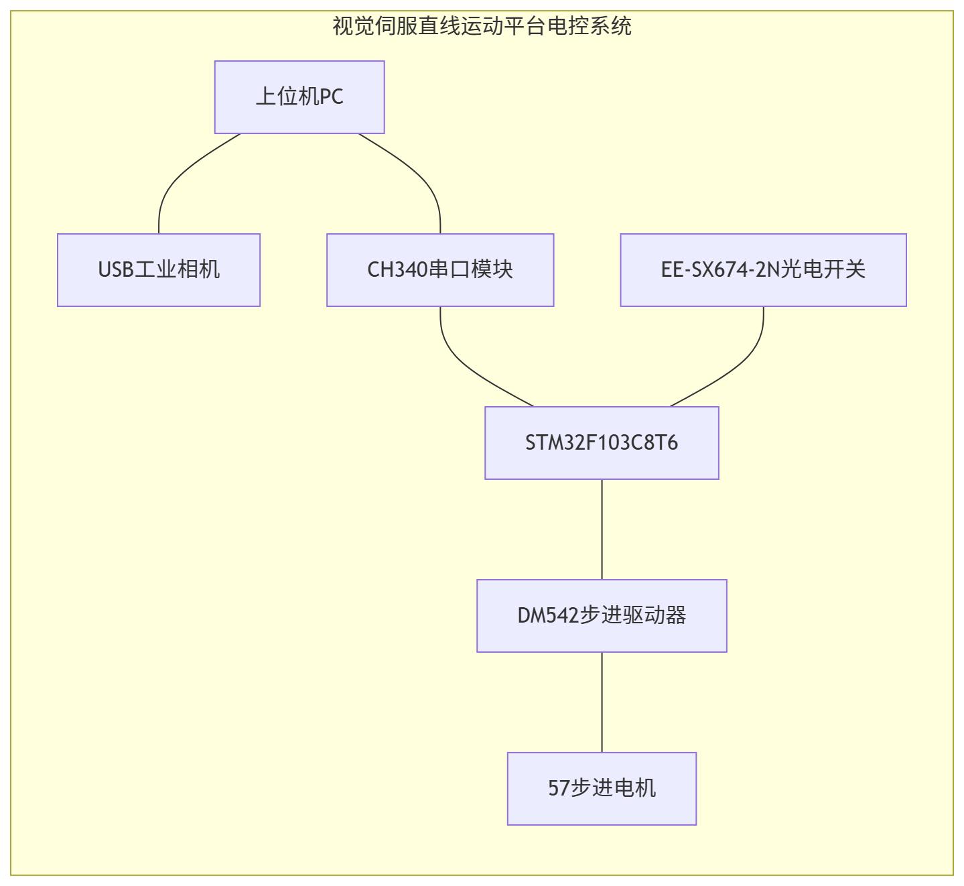
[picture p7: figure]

图 3-1 电控系统硬件连接关系图

## 3.2 STM32 引脚分配

STM32F103C8T6 为 48 引脚 LQFP 封装，根据系统功能需求，各引脚分配如表
3-1 所示。

第四章

表 3-1 STM32 引脚功能分配表

引脚 | 功能 | 说明

PA8

## TIM1_CH1 PWM

| 输出 | 脉冲信号输出至 DM542 的 PUL-端
PB5 | GPIO 输出 | 方向控制，低电平正转，高电平反转
PB10 | GPIO 输入（上拉） | 负限位/零点光电开关（触发低电平）
PB11 | GPIO 输入（上拉） | 正限位光电开关（触发低电平）
PA9 | USART1_TX | 串口发送（备用调试）
PA10 | USART1_RX | 串口接收，接 CH340 模块的 TX
PA13 | SWDIO | 程序下载与调试
PA14 | SWCLK | 程序下载与调试
VDD/VSS | 电源 | 3.3V 供电及接地

## 3.3 关键电路设计

3.3.1 共阳极步进驱动接口

DM542 驱动器采用共阳极接法，PUL+和 DIR+引脚并联后接+5V 电源，PUL-和

DIR-分别接 STM32 的 PA8 和 PB5。当 STM32 输出低电平时，驱动器输入侧形成电

流回路，触发对应信号；输出高电平时无电流，信号无效。这种接法的优势在于驱动 器输入端已内置限流电阻，可直接连接 5V 或 3.3V 逻辑电平，无需额外电平转换电

路，接线简洁可靠。由于 STM32 的 GPIO 为 3.3V 逻辑，输出高电平时与+5V 之间存

在约 1.7V 压差，驱动器输入端在此电压下不会产生误导通电流，工作稳定[3]。图 3-2

为共阳极接口电路。

第四章

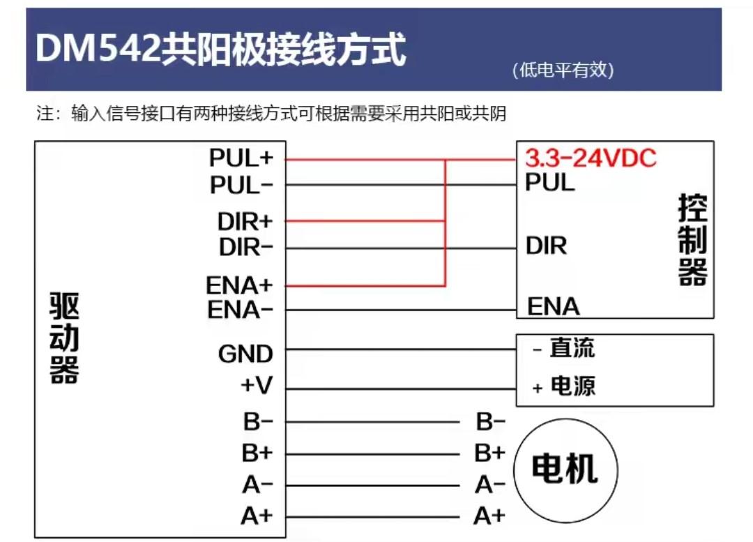
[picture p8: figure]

图 3-2 共阳极接口电路

3.3.2 限位开关输入接口

EE-SX674-2N 为 NPN 常开型光电开关，集电极开路输出。无遮挡时内部三极管

截止，输出端由上拉电阻拉至高电平（3.3V）；遮挡时内部三极管导通，输出端被拉

低至 GND。STM32 的 PB10 和 PB11 配置为浮空输入模式并开启内部上拉电阻，可

直接检测开关状态变化。该方案无需外部上拉电阻，简化了电路设计。为提高抗干扰 能力，在 PCB 布线时应在输入信号线上靠近 STM32 引脚处放置 100nF 滤波电容，以

消除开关动作时可能产生的抖动噪声。两个限位开关分别安装于模组两端，其电气连

接方式完全一致。

3.3.3 串口通信接口

CH340 模块将上位机 USB 信号转换为 TTL 电平串口信号，其 TX 端接 STM32

的 PA10（RX），RX 端接 PA9（TX）。模块工作电压为 3.3V 或 5V 兼容，本设计选

用 3.3V 供电模式，与 STM32 逻辑电平匹配，无需电平转换。波特率固定为 115200bps，

数据位 8 位、停止位 1 位、无校验。

## 3.4 供电方案

系统需提供多级电源：220V交流市电经 24V 开关电源转换为直流 24V，为 DM542

驱动器主回路供电；24V 经 DC-DC 模块降压至 5V，为光电开关及 CH340 模块供电；

第四章

5V 经 STM32 板载 LDO 稳压至 3.3V，为 STM32 芯片及其外围电路供电。各电源模

块的 GND 需单点共地，确保信号参考电位一致。驱动器主回路与控制回路之间通过

光耦隔离，有效防止电机启停时产生的反向电动势干扰控制信号[4]。图 3-3 为供电拓

扑图。

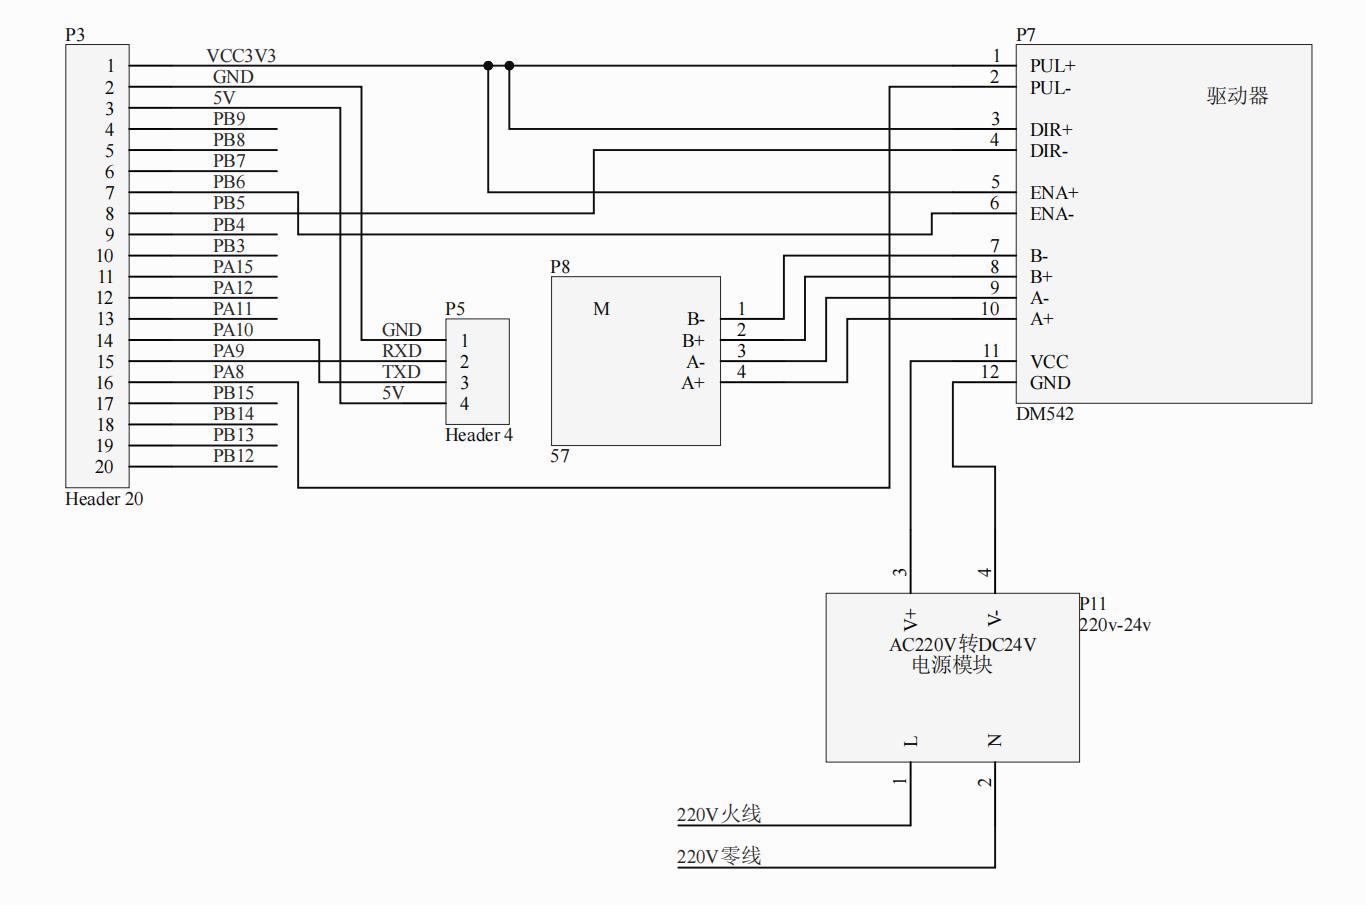
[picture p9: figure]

图 3-3 供电拓扑图

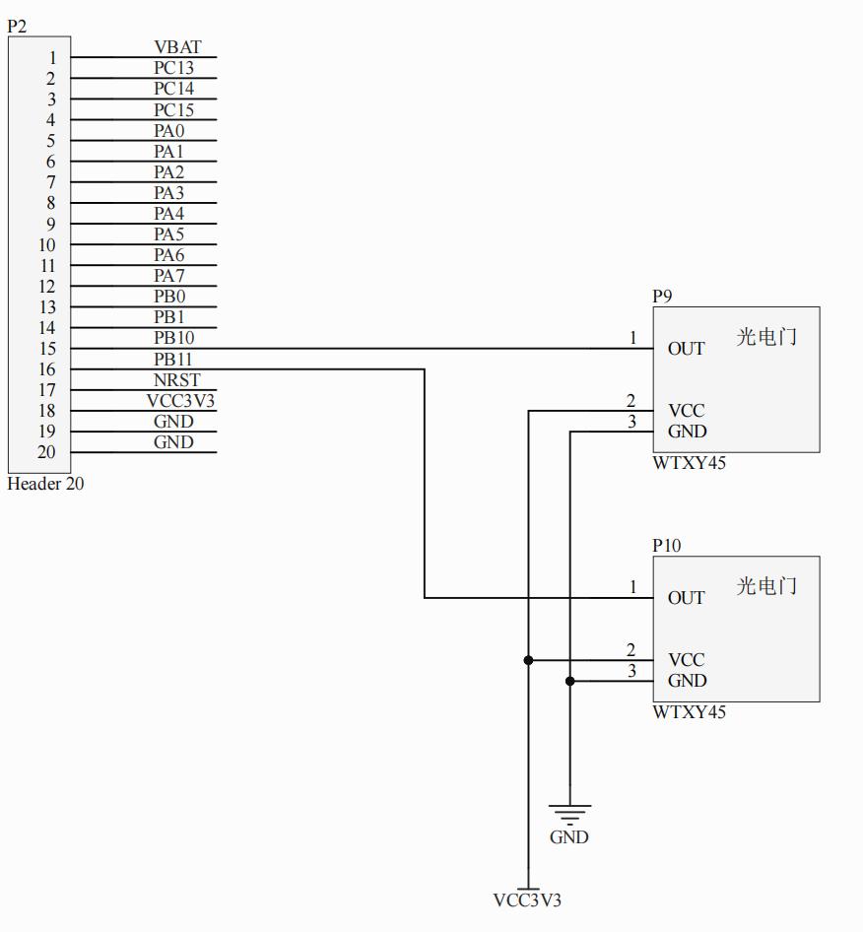
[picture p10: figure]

图 3-4 供电拓扑图

第四章

## 3.5 电气接线总图说明

系统电气接线遵循强弱电分离原则：24V 驱动回路（DM542 至步进电机）使用

0.75mm²导线，与控制信号线（0.15mm²）分开走线，避免电磁干扰。所有信号线均

采用屏蔽线，屏蔽层单端接地。接线端子采用插拔式接线排，便于调试时更换组件。

全部接线完成后需进行对地绝缘测试和短路测试，确认无误后方可通电调试。

## 3.6 本章小结

本章完成了电控系统的硬件设计，明确了 STM32 各引脚的信号定义与功能分配，

设计了共阳极步进驱动接口电路、光电限位开关输入电路及串口通信电路，规划了三

级供电方案并说明了共地要求与抗干扰措施。电气接线遵循强弱电分离原则，为后续 程序开发与系统调试提供了硬件基础[3][4][6]。

第五章

## 第四章 程序说明

## 4.1 上位机程序结构与流程

上位机程序基于 Python 语言开发，采用 OpenCV 进行图像处理，pyserial 实现串

口通信。程序启动后首先执行初始化操作：调用 find_ch340_port 函数自动识别 CH340

串口端口并建立连接，同时打开 USB 工业相机（1080p/30fps）。完成初始化后进入

主循环，每个周期执行键盘事件检测、图像采集、目标识别与偏差计算、串口指令发 送以及界面刷新等任务[2]。

视觉识别是上位机程序的核心功能模块。程序将采集到的 BGR 图像转换至 HSV

颜色空间，针对红色目标设定两组阈值范围（0~10 和 160~180）分别提取掩膜，合并

后通过形态学开运算和闭运算消除噪点与孔洞，最后提取最大轮廓并获得其质心坐标 [2]。若目标未被检测到或轮廓面积小于 100 像素，则判定为无目标。调试信息通过

cv2.imshow 实时显示，包括画面中心十字线、目标位置标记、偏差值、当前模式和速

度档位。

控制逻辑区分手动与自动两种模式。手动模式下，程序响应键盘事件：W 键发

送正转指令，S 键发送反转指令，空格键发送停止指令，E 键切换急停状态，Z 键发

送调零指令，0~9 键调节速度档位。每次手动操作后记录最后操作时刻。当空闲计时

超过 1 秒且当前处于停止状态时，程序自动切换至自动对准模式。自动模式下，程序

计算目标质心与画面中心水平偏差 dx，若|dx|小于 15 像素（死区）则发送停止指令；

若 dx>0（目标偏右）发送反转指令使平台左移；若 dx<0（目标偏左）发送正转指令

使平台右移。自动模式下速度固定为 3 档（约 35rpm），以防止因相机帧率限制导致

系统振荡[6]。图 4-1 为上位机程序主循环流程图。

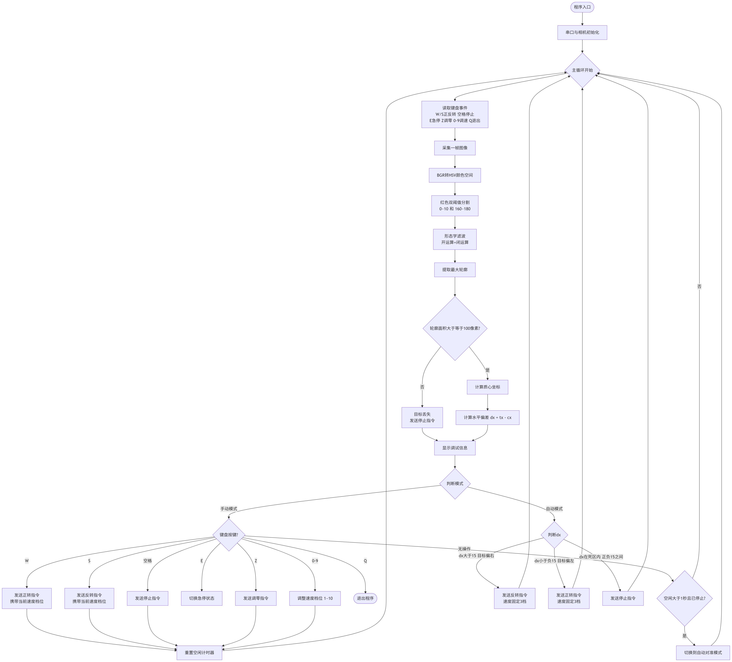
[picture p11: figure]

图 4-1 上位机程序主循环流程图

## 4.2 通信协议

上下位机通信采用固定 4 字节帧格式：第 1 字节为帧头 0xAA，第 2 字节为命令

码，第 3 字节为数据载荷，第 4 字节为校验和（取帧头、命令码、数据三者和的低 8

位）。命令码定义如下：0x01 正转、0x02 反转、0x03 停止、0x04 急停、0x05 调零。

速度档位（1~10）作为数据载荷随正转或反转指令一并发送。该协议结构简单，解析

开销小，适合通过低速串口在视觉反馈周期内频繁传输控制指令[5]。

表 4-1 下位机串口命令表

功能 | 命令码 | 档位数据 | 完整指令 (HEX) | 校验和
正转 1 档 | 0x01 | 0x01 | AA 01 01 AC | 0xAC
正转 2 档 | 0x01 | 0x02 | AA 01 02 AD | 0xAD
正转 3 档 | 0x01 | 0x03 | AA 01 03 AE | 0xAE
正转 4 档 | 0x01 | 0x04 | AA 01 04 AF | 0xAF
正转 5 档 | 0x01 | 0x05 | AA 01 05 B0 | 0xB0
正转 6 档 | 0x01 | 0x06 | AA 01 06 B1 | 0xB1
正转 7 档 | 0x01 | 0x07 | AA 01 07 B2 | 0xB2
正转 8 档 | 0x01 | 0x08 | AA 01 08 B3 | 0xB3
正转 9 档 | 0x01 | 0x09 | AA 01 09 B4 | 0xB4
正转 10 档 | 0x01 | 0x0A | AA 01 0A B5 | 0xB5
反转 1 档 | 0x02 | 0x01 | AA 02 01 AD | 0xAD
反转 2 档 | 0x02 | 0x02 | AA 02 02 AE | 0xAE
反转 3 档 | 0x02 | 0x03 | AA 02 03 AF | 0xAF
反转 4 档 | 0x02 | 0x04 | AA 02 04 B0 | 0xB0
反转 5 档 | 0x02 | 0x05 | AA 02 05 B1 | 0xB1
反转 6 档 | 0x02 | 0x06 | AA 02 06 B2 | 0xB2
反转 7 档 | 0x02 | 0x07 | AA 02 07 B3 | 0xB3
反转 8 档 | 0x02 | 0x08 | AA 02 08 B4 | 0xB4
反转 9 档 | 0x02 | 0x09 | AA 02 09 B5 | 0xB5

功能 | 命令码 | 档位数据 | 完整指令 (HEX) | 校验和
反转 10 档 | 0x02 | 0x0A | AA 02 0A B6 | 0xB6
停止 | 0x03 | 0x00 | AA 03 00 AD | 0xAD
急停 | 0x04 | 0x00 | AA 04 00 AE | 0xAE
调零 | 0x05 | 0x00 | AA 05 00 AF | 0xAF

## 4.3 下位机程序结构与中断服务

下位机程序基于 Keil MDK 开发，采用 STM32 标准外设库。主函数中首先完成

系统时钟、GPIO、定时器、串口及中断优先级的初始化，随后自动进入调零状态：

电机以 3 档低速反转运行，直至 PB10 检测到负限位触发，电机停止并将位置变量清

零，完成回零操作后进入主循环等待上位机指令[4]。

串口接收采用中断方式。当 USART1 收到 4 字节数据后，在中断服务程序中完

成帧头验证和校验和检查，校验通过后调用命令处理函数解析指令并执行相应操作： 正转或反转指令根据数据载荷设置速度档位并启动电机；停止指令关闭 PWM 输出；

急停指令立即停止电机并置标志位；调零指令则重新触发回零状态机。

脉冲输出由 TIM1 的 PWM 模式实现，通过 ARR 寄存器的值控制脉冲频率，经

查表方式在 10 档速度间快速切换（对应 15~200rpm）。TIM1 的更新中断用于位置计

数：每产生一个脉冲即根据方向标志对位置变量递增或递减。限位保护通过主循环中 定时读取 PB10 和 PB11 电平状态实现，当检测到对应限位触发时立即调用急停函数，

确保平台不超出行程范围[5]。图 4-2 为下位机主程序及中断服务流程图。

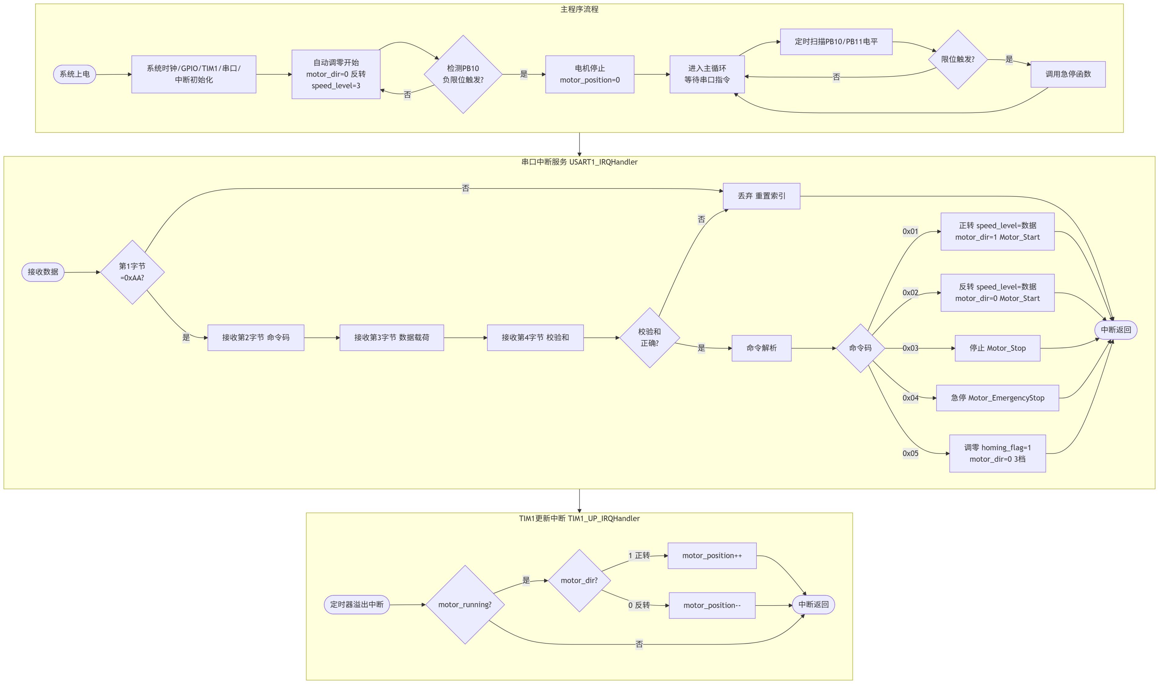
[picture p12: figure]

图 4-2 下位机主程序及中断服务流程图

## 4.4 本章小结

本章说明了上下位机程序的核心架构与关键逻辑。上位机程序基于 Python+OpenCV 实现 HSV 阈值分割、目标质心提取、手动/自动模式切换及串口指令

发送；下位机程序基于 STM32 实现串口指令解析、PWM 脉冲输出、方向控制、位

置计数及限位保护。双方通过固定 4 字节帧格式通信，协议简洁可靠，共同构成了完

整的视觉伺服控制系统软件链路[2][4][5][6]。

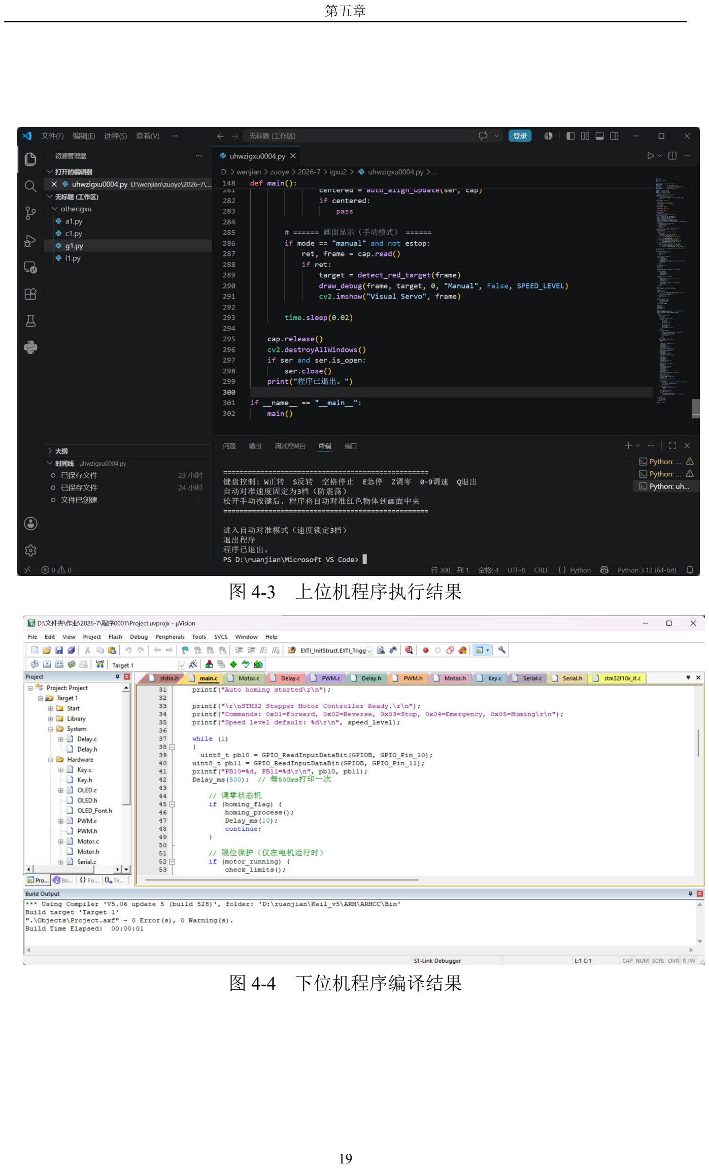
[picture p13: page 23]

图 4-3 上位机程序执行结果

图 4-4 下位机程序编译结果

## 第五章 装配调试过程

## 5.1 机械系统组装

机械系统的组装在实验室操作台上进行。首先将 ECB80D 欧规皮带模组主体固

定于平台基板上，确保模组底座与基板贴合紧密、无翘曲，用内六角螺钉依次紧固。 随后安装 57 步进电机及 7:1 减速器组合体，使减速器输出轴与同步轮轴孔对准，以

联轴器连接并紧固顶丝，确保动力传递路径同轴度良好。同步带 S5M1812 沿模组导

轨方向张紧于两端的同步轮上，通过调节模组端部的张紧螺栓调整皮带预紧力，以皮 带在负载启动时不发生跳齿、且在手动按压时约有 1~2mm 弹性变形量为宜。滑块沿

导轨全程推动时应感觉均匀顺滑、无明显阻尼波动。

L 型工业相机支架采用 PLA 制作，支架底座固定于操作台或模组基板上，立臂

与横臂通过直角连接件构成 L 形结构，横臂末端安装相机固定座。安装时需保证横臂

伸出方向与模组运动方向垂直，相机镜头光轴垂直于模组运动平面，且视野中心大致

对准模组行程中点。支架连接处均使用防松螺母或螺纹胶加固，确保相机在运行过程 中不因振动而晃动。将 USB 工业相机固定于支架末端的相机座上，调整镜头焦距使

在 0.3~1m 工作距离内画面清晰，光圈调整至亮度适中。图 5-1 为平台整体机械装配

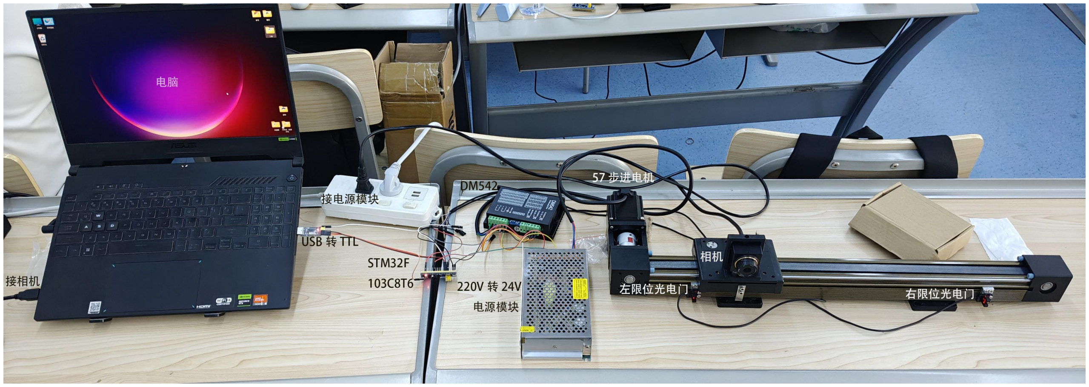
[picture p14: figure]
示意图。

图 5-1 平台整体机械装配示意图

## 5.2 电气接线

按照第三章设计的电气接线图完成全部电气连接。电气接线遵循先控制回路后主 回路的原则：首先完成 STM32 最小系统板与 CH340 模块、光电开关、DM542 驱动

器之间的信号线连接，共阳极接法中 PUL+与 DIR+并联后接 5V，PUL-接 PA8，DIR- 接 PB5，PB10 和 PB11 分别接两个光电开关的输出端。各信号线采用 0.15mm²多股

软线，端子处压接杜邦头或冷压端子以确保接触可靠。

随后连接主回路：24V 开关电源输出端正极接 DM542 驱动器的 VCC 端，负极

接 GND 端，电机 A+、A-、B+、B-四根线按驱动器标识对应连接。注意断电状态下

进行接线操作，全部接线完成后使用万用表检查各电源对地是否有短路，确认无误后 方可通电。通电后首先测量各电压节点：DM542 的 VCC 与 GND 应为 24V，STM32

的 3.3V 和 5V 输出应正常，CH340 模块指示灯应亮起，表明供电正常[3]。

## 5.3 调试过程

5.3.1 下位机独立调试

关闭上位机，使用串口助手（如 SSCOM）直接向 STM32 发送十六进制指令帧

进行功能验证。发送调零指令 0xAA 0x05 0x00 0xAF，观察平台是否向负限位方向运

动并在触发 PB10 后停止。若方向相反，交换步进电机 A+与 A-或修改程序中 motor_dir

## 的默认值。发送正转指令 0xAA 0x01 0x05 0xB0（5 档）和反转指令 0xAA 0x02 0x05

0xB1，验证方向控制是否正确。用手遮挡正限位光电开关，平台应立即停止，说明

限位保护生效。串口助手应能接收到 STM32 发送的 printf 调试信息（如"Forward, speed

level: 5"），表明串口通信正常[4]。

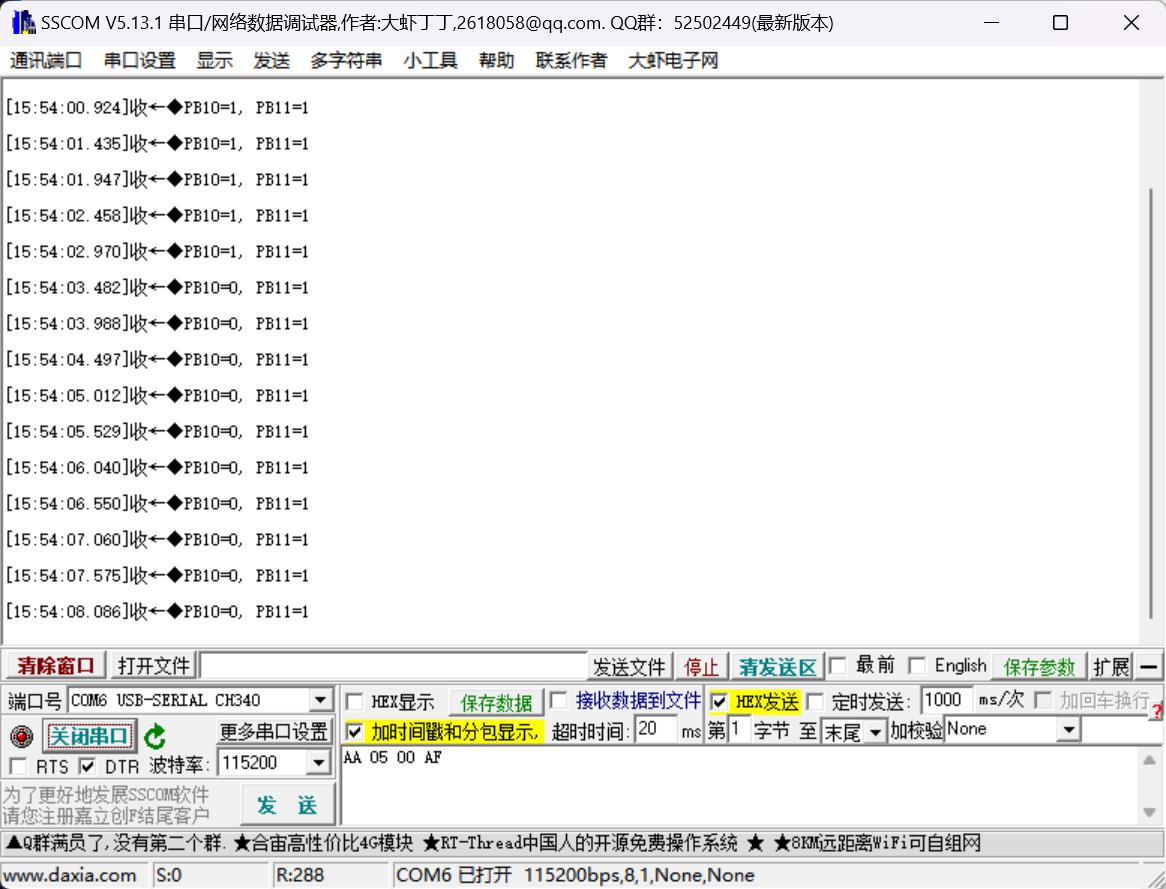
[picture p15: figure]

图 5-2 SSCOM 串口助手 运动到左限位时接收的信号

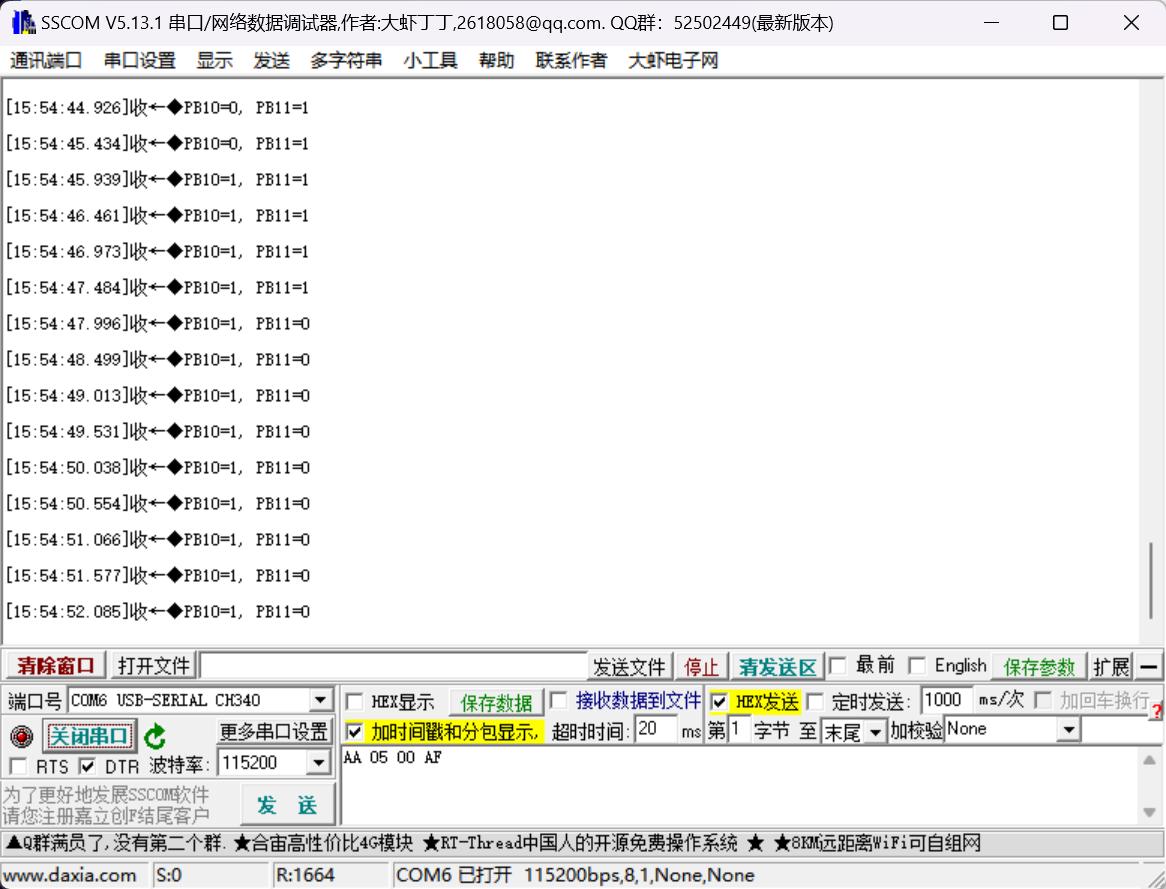
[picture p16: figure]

图 5-3 运动到右限位时接收的信号

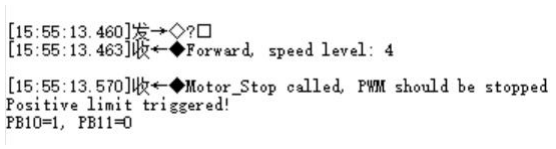
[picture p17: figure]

图 5-4 执行四档前进命令

图 5-5 执行五档后退命令

图 5-5 执行停止命令

图 5-6 执行急停命令

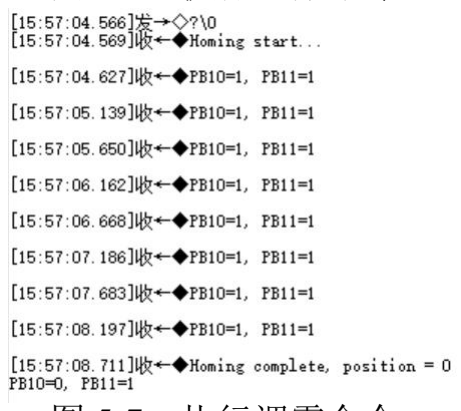
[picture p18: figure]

图 5-7 执行调零命令

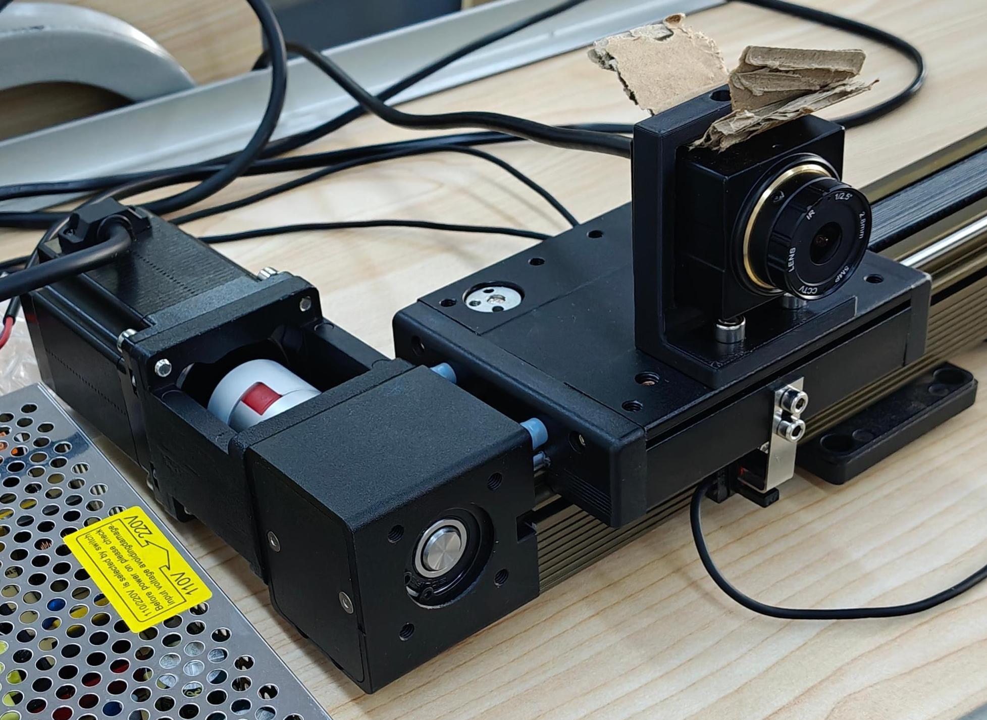
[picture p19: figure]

图 5-8 调零命令结束的电机位置

5.3.2 上位机独立调试

关闭下位机供电，运行上位机 Python 程序。观察摄像头画面能否正常显示，在

画面中放置红色目标物，调试 HSV 阈值参数（红色阈值范围为 0~10 和 160~180），

确保目标物区域被正确分割并用绿色圆圈标记质心。在无目标时画面应显示"No

target!"提示。调整目标物位置，观察画面中央十字线和偏差数值是否正确变化，验证

视觉识别功能的正确性[2]。

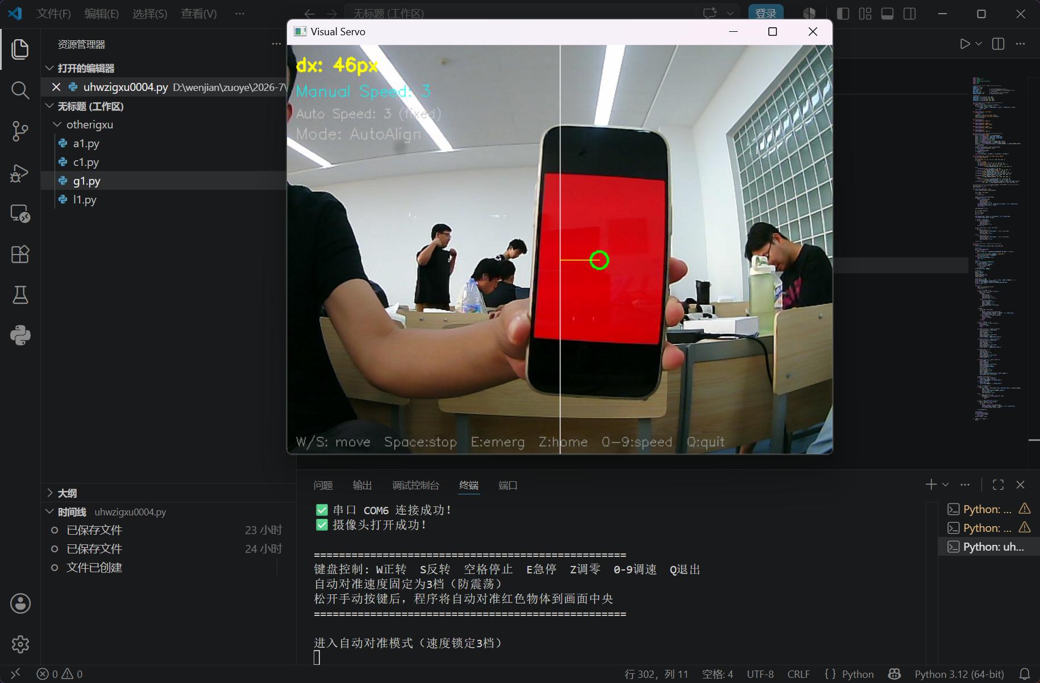
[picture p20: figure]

图 5-9 上位机对红色物体的识别结果

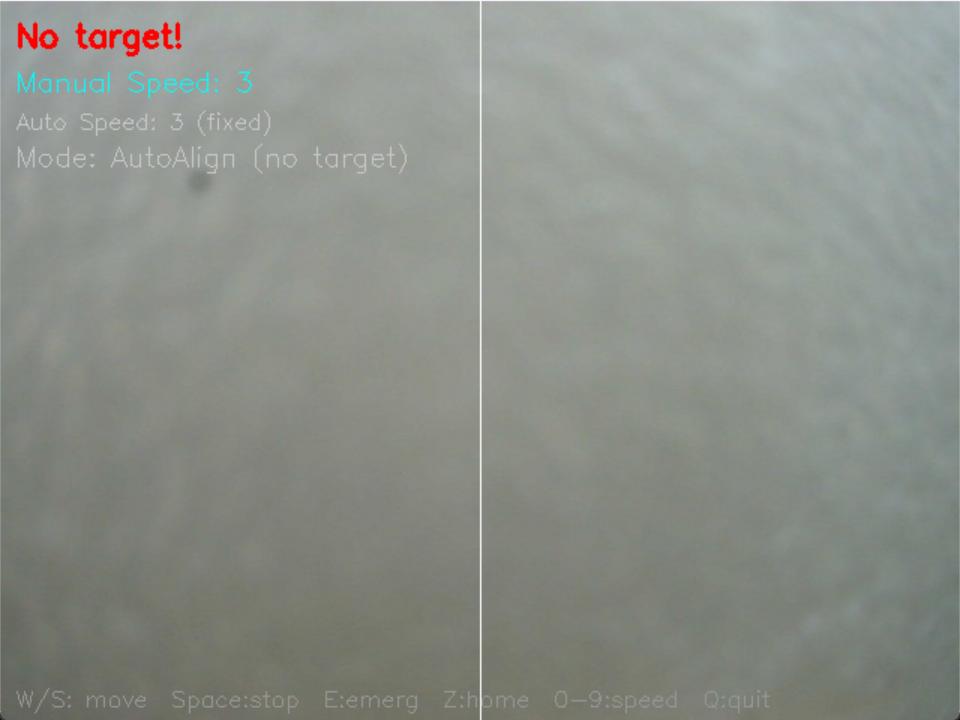
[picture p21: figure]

图 5-10 上位机对无红色物体的识别结果

5.3.3 联调

上下位机同时上电，运行完整程序。按下 W 键，平台应正向运动；按 S 键反向

运动；空格键停止。按 Z 键平台应反转运行至负限位后停止并清零位置。将红色目标

物放置于视野范围内，等待 1 秒空闲后系统自动切换至自动对准模式，观察平台是否

自动移动使红色目标趋于画面中心。若出现振荡，可适当增大死区 DEAD_ZONE 值

（从 15 增至 20 或 25）；若响应过于迟钝，可适当提高自动模式速度档位（从 3 调

至 4）。反复调整死区与速度参数，使平台能快速、平稳地将目标对准至画面中心[6]。

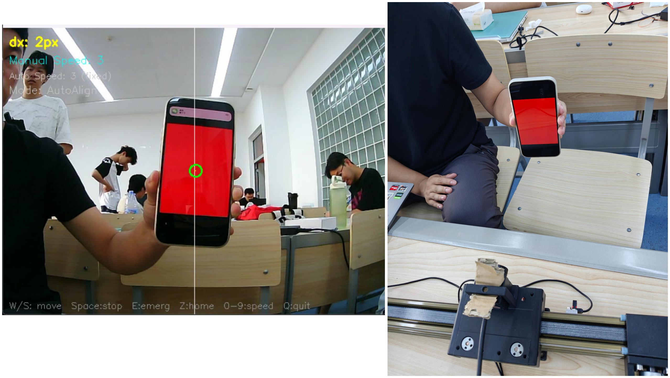
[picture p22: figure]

图 5-10 自动对准结果

## 5.4 调试中的问题与解决

在系统联调过程中，遇到了一系列软硬件问题，通过逐项排查与分析，均在调试

阶段得以解决。现将主要问题及解决措施记录如下，供后续类似系统开发时参考。

（1）电机不转，驱动器无反应

首次通电后，按下正转按键电机无任何动作。排查顺序为：先用万用表确认 DM542 驱动器的 24V 供电正常，再检查 PUL+与 DIR+是否已接+5V（共阳极接法要

求），最后用示波器测量 PA8 引脚是否有 PWM 波形输出。经检查发现 PUL+与 DIR+

并联接+5V 处存在虚焊，重新焊接后电机正常运转。

（2）电机方向与预期相反

按下正转键时平台向负方向运动，说明方向逻辑反相。解决方法有两种：一是交 换步进电机 A+与 A-两相线，二是修改程序中 motor_dir=1 对应的 GPIO 输出电平。

本设计采用前者，在驱动器端直接交换 A+与 A-接线即可。

（3）电机在调零完成后仍然缓慢转动

调零触发限位开关后调用 Motor_Stop()函数停止电机，但电机仍有缓慢转动。排

## 查发现 PWM_Stop()函数仅关闭了定时器计数使能 TIM_Cmd(TIM1， DISABLE)，而 未关闭 PWM 主输出 TIM_CtrlPWMOutputs(TIM1， DISABLE)，导致定时器停止后

输出引脚仍保持之前的电平状态，驱动器持续接收到无效信号而产生误动作。在 PWM_Stop()中补充主输出关闭后问题解决。

（4）自动对准方向与期望相反

红色目标位于画面右侧时，系统判断 dx>0，按逻辑应使平台向左移动（反转）

以追回目标，但平台却向右移动，导致偏差越来越大。原因为上位机发送指令的逻辑 写反：dx>0 时错误地发送了正转指令。将条件判断修正为“dx>0 时发反转，dx<0 时

发正转”后方向正确。

（5）手动按键控制被自动模式频繁打断

按下 W 或 S 键后，平台仅运动了极短时间便被自动对准模式接管，无法持续手

动控制。原因在于主循环每次都会检查空闲计时，只要计时超过 1 秒就切换到自动模

式，而手动按键后未重置空闲计时器。在每次手动按键处理分支中增加重置空闲计时 器的操作后，手动控制可连续执行，且停止操作 1 秒后自动切换至对准模式。

（6）急停后状态混乱，无法恢复正常控制

按下 E 键急停后，平台停止运动，但再次按 E 键解除急停后，所有按键操作均

无响应。原因是急停解除后未正确重置控制状态标志位，系统仍停留在急停锁止状态。

## 在急停解除分支中增加标志位重置操作（last_stop_sent = False、mode = "manual"、 manual_stopped = True）后恢复正常。

（7）自动对准时电机频繁启停，产生异响

自动对准模式下，上位机每帧（约 50Hz）都根据偏差发送指令，导致电机频繁

启停换向，产生明显异响。优化措施：一是引入 last_dir_sent 变量记录上一次发送的

方向，仅在方向发生改变时才发送新指令；二是将自动对准的调用频率从每帧一次降 低至每 5 帧一次（约 10Hz）。优化后电机运行噪声显著降低，运动平稳性改善。

（8）红色阈值在自然光照变化时识别不稳定

实验室自然光照在一天中变化较大，早晨与下午的 HSV 阈值需要重新调整。通

过在程序中增加形态学滤波（开运算与闭运算）消除噪点和填充孔洞，并适当缩小阈

值范围以减少误检，同时配合室内遮光措施使环境光照相对稳定，最终保证了视觉识

别的可靠性。

## 5.5 本章小结

本章详细说明了从机械组装、电气接线到逐级调试的完整过程。机械组装重点保

证了传动链的刚性与相机支架的稳固性；电气接线遵循先控制后主回路的顺序并完成

了通电检查；调试过程按照下位机独立调试、上位机独立调试、联调三个步骤依次展

开，有效缩小了故障排查范围。针对调试中出现的皮带跳齿、阈值不稳定、通信错误

等问题采取了相应解决措施，最终系统各项功能运行正常，为后续课程设计的实验演

示奠定了基础[2][3][4][6]。

第六章

## 第六章 设计总结

## 6.1 完成的工作

本次课程设计完成了视觉伺服直线运动平台从方案论证到实物调试的全流程开 发。在机械设计方面，完成了 ECB80D 同步带模组的选型计算、7:1 减速比的确定、

57 步进电机的扭矩与惯量校核以及 L 型相机支架的结构设计，绘制了整机装配图与

支架零件图。在电控设计方面，完成了 STM32F103C8T6 的引脚分配、共阳极步进驱

动接口电路设计、光电限位开关输入电路设计及三级供电方案规划，绘制了电气接线 图。在软件开发方面，完成了上位机 Python+OpenCV 视觉识别程序（含 HSV 阈值分

割、轮廓提取、质心计算、手动/自动模式切换及串口通信）和下位机 STM32 脉冲输

出、方向控制、限位保护及位置计数程序的开发与联调。

系统调试阶段按照“下位机独立调试→上位机独立调试→上下位机联合调试”的

步骤依次推进，逐项排查并解决了电机不转、方向反相、调零后无法停止、自动对准

方向错误、手动控制被频繁打断、急停状态恢复异常、电机频繁启停异响以及光照变 化导致识别不稳定等问题。最终系统实现了初始化回零、手动点动控制（W/S 正反转、

空格停止、0~9 调速）、急停保护（E 键）、空闲自动对准（红色目标跟踪）及限位

安全保护等功能，各项运行状态正常，达到了课程设计的预期目标。

## 6.2 主要收获

在知识层面，本次设计加深了对机电一体化系统各组成部分之间相互关系的理

解。过去的学习中，机械原理、电工电子、控制理论、传感器技术等课程相对独立，

通过本次设计将这些知识串联了起来：同步带的选型直接影响电机扭矩和惯量匹配，

驱动器的细分设置决定了系统分辨率，视觉检测的稳定性决定了控制指令的准确性，

串口通信的速率又限制了系统的响应带宽。这些环节环环相扣，任何一个环节的参数

变动都会影响整体性能，这种系统性思维是在课堂学习中难以获得的。

在工程能力层面，本次设计锻炼了从理论计算到工程实现的完整能力。方案论证

阶段需要从多个可行方案中比较取舍，结构计算阶段需要将设计指标逐项分解到每个 零部件，程序开发阶段需要在 Python 与 C 语言之间切换并保证通信协议的一致性，

第六章

装配调试阶段则需要综合运用万用表、示波器、串口助手等多种工具进行故障定位。

特别是在调试过程中，学会了通过分步独立调试缩小故障范围的方法，也积累了大量 实际问题（如共阳极接线确认、PWM 主输出关闭、状态标志位重置等细节）的处理

经验。这些经历为今后从事更复杂的机电系统开发奠定了重要基础。

## 6.3 不足与改进方向

受实验室设备条件限制，本设计仍存在若干可改进之处。一是未配备编码器，系

统目前为开环驱动，位置反馈仅靠脉冲计数，无法有效补偿皮带弹性变形和机械间隙 带来的定位误差，后续若增加 E6B2 编码器接口即可构成全闭环位置控制，并引入 PI

调节算法进一步改善定位精度[3][5]。二是视觉识别基于 HSV 阈值分割，对环境光照变

化较为敏感，后续可引入基于深度学习的目标检测算法（如 YOLO 系列）以提高环

境适应性和识别鲁棒性[2][4]。三是串口通信速率有限，限制了视觉反馈周期的进一步

缩短，后续可考虑采用 USB 虚拟串口或以太网方式提高通信带宽。

尽管存在以上不足，当前系统已在给定条件下实现了视觉伺服闭环控制的核心功

能——通过视觉检测驱动平台自动将红色目标对准至画面中心，证明了方案的可行

性。本次课程设计的完整流程也让自己认识到，工程实践中往往需要在理想方案与现

有条件之间寻找平衡，在条件有限的情况下优先确保核心功能的实现，其余优化可在

后续迭代中逐步完成。

第六章

## 参考文献

[1] 周俊宇，夏琳燕，周全，黄俊. 基于运动控制卡和工业视觉的综合实训平台设计[J]. 长沙大学学报，2021，35(5)：29-33. [2] 解彬彬，孟鑫朋，曹洪玮，彭赟，郭俊先，牛长河，孙久旭，潘晓宇. 农业采摘

机器人视觉-伺服抓取实验平台设计与教学应用[J]. 新疆农机化，2026(3)：53-61. [3] 黄建军，邵中魁，陶仁和，姜耀林. 基于单片机的位置实时精调伺服控制系统开

## 发[J]. 精密制造与自动化，2021(3)：18-22. [4] 马福阳，申迎风，蒋博，杨莹莹，王椋栩. 基于 STM32F103C8T6 的 YOLOV5 目

标检测与喷涂控制系统设计[J]. 电子技术，2026，55(2)：876-877. [5] 王焕云，李慨. 基于网络直角坐标机器人视觉伺服控制系统理论研究[J]. 沧州师

范专科学校学报，2005，21(4)：85-88. [6] 杨军莉. 基于工业机器人视觉伺服控制系统研究[J]. 自动化技术与应用，2020，

39(8)：66-69.

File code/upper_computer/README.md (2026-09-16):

# 上位机程序说明

## 环境要求
- Python 3.8+
- 依赖见 requirements.txt

## 安装依赖
```bash
pip install -r requirements.txt
```
## 流程图

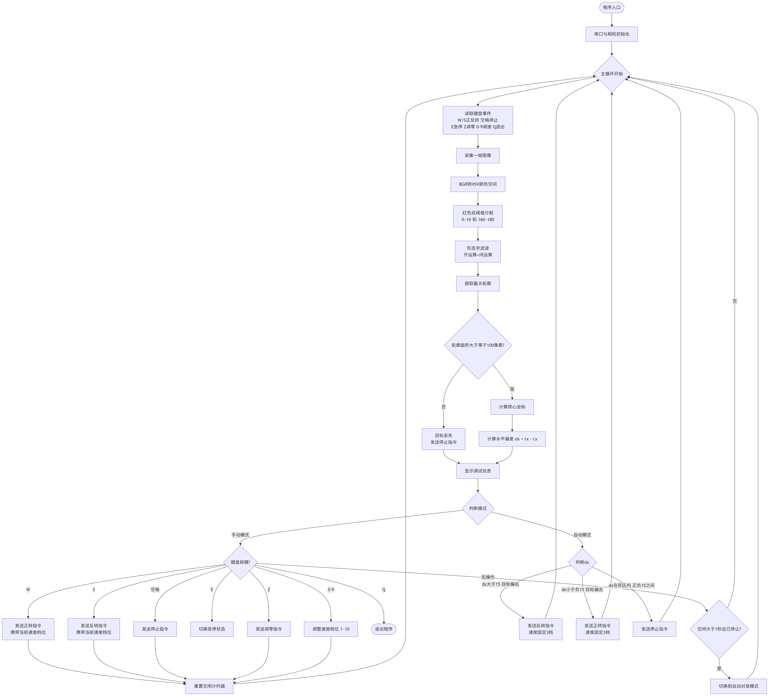
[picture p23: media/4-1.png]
程序流程图


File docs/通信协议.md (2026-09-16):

# 视觉伺服直线运动平台 — 上下位机通信协议

## 1. 物理层

| 项目 | 参数 |
|:---|:---|
| 接口 | USB 转 TTL（CH340） |
| 下位机串口 | USART1：PA9 (TX)、PA10 (RX) |
| 波特率 | 115200 |
| 数据位 | 8 |
| 停止位 | 1 |
| 校验位 | 无 |
| 流控 | 无 |
| 通信方式 | 上位机（PC）→ 下位机（STM32）单向控制；下位机→上位机为 ASCII 调试信息 |

> 接线注意：USB 转 TTL 的 TX 接 PA10，RX 接 PA9，GND 必须共地。

---

## 2. 帧格式

上位机发送的控制帧固定为 4 字节：

| 字节偏移 | 字段 | 长度 | 说明 |
|:---:|:---|:---:|:---|
| 0 | 帧头 | 1 | 固定 `0xAA` |
| 1 | 命令码 | 1 | 见命令总表 |
| 2 | 数据 | 1 | 速度档位 `0x01~0x0A`，或 `0x00` |
| 3 | 校验和 | 1 | `(0xAA + 命令码 + 数据) & 0xFF` |

校验和公式：

校验和 = (0xAA + 命令码 + 数据) & 0xFF

---

## 3. 命令总表

| 功能 | 命令码 | 数据 | 完整帧（HEX） | 校验和 |
|:---|:---:|:---:|:---|:---:|
| 正转 1 档 | `0x01` | `0x01` | `AA 01 01 AC` | `0xAC` |
| 正转 2 档 | `0x01` | `0x02` | `AA 01 02 AD` | `0xAD` |
| 正转 3 档 | `0x01` | `0x03` | `AA 01 03 AE` | `0xAE` |
| 正转 4 档 | `0x01` | `0x04` | `AA 01 04 AF` | `0xAF` |
| 正转 5 档 | `0x01` | `0x05` | `AA 01 05 B0` | `0xB0` |
| 正转 6 档 | `0x01` | `0x06` | `AA 01 06 B1` | `0xB1` |
| 正转 7 档 | `0x01` | `0x07` | `AA 01 07 B2` | `0xB2` |
| 正转 8 档 | `0x01` | `0x08` | `AA 01 08 B3` | `0xB3` |
| 正转 9 档 | `0x01` | `0x09` | `AA 01 09 B4` | `0xB4` |
| 正转 10 档 | `0x01` | `0x0A` | `AA 01 0A B5` | `0xB5` |
| 反转 1 档 | `0x02` | `0x01` | `AA 02 01 AD` | `0xAD` |
| 反转 2 档 | `0x02` | `0x02` | `AA 02 02 AE` | `0xAE` |
| 反转 3 档 | `0x02` | `0x03` | `AA 02 03 AF` | `0xAF` |
| 反转 4 档 | `0x02` | `0x04` | `AA 02 04 B0` | `0xB0` |
| 反转 5 档 | `0x02` | `0x05` | `AA 02 05 B1` | `0xB1` |
| 反转 6 档 | `0x02` | `0x06` | `AA 02 06 B2` | `0xB2` |
| 反转 7 档 | `0x02` | `0x07` | `AA 02 07 B3` | `0xB3` |
| 反转 8 档 | `0x02` | `0x08` | `AA 02 08 B4` | `0xB4` |
| 反转 9 档 | `0x02` | `0x09` | `AA 02 09 B5` | `0xB5` |
| 反转 10 档 | `0x02` | `0x0A` | `AA 02 0A B6` | `0xB6` |
| 停止 | `0x03` | `0x00` | `AA 03 00 AD` | `0xAD` |
| 急停 | `0x04` | `0x00` | `AA 04 00 AE` | `0xAE` |
| 调零 | `0x05` | `0x00` | `AA 05 00 AF` | `0xAF` |

> 注意：`0x0A` 表示第 10 档，不是换行符；发送时必须使用 HEX 模式，且不要勾选“加回车换行”。

---

## 4. 速度档位说明

| 档位 | 数据值 | 说明 |
|:---:|:---:|:---|
| 1 | `0x01` | 最慢 |
| 2 | `0x02` | 慢 |
| 3 | `0x03` | 较慢（自动对准固定使用） |
| 4 | `0x04` | 中慢 |
| 5 | `0x05` | 中速 |
| 6 | `0x06` | 中快 |
| 7 | `0x07` | 快 |
| 8 | `0x08` | 较快 |
| 9 | `0x09` | 很快 |
| 10 | `0x0A` | 最快 |

---

## 5. 下位机返回信息

下位机通过串口返回 ASCII 文本，仅用于调试和状态提示，不属于二进制控制协议。

| 返回信息 | 含义 |
|:---|:---|
| `STM32 Stepper Motor Controller Ready.` | 系统启动就绪 |
| `Forward, speed level: X` | 正转，速度档位 X |
| `Reverse, speed level: X` | 反转，速度档位 X |
| `Stop` | 停止 |
| `Emergency Stop!` | 急停 |
| `Homing start...` | 开始调零 |
| `Homing complete, position = 0` | 调零完成，位置归零 |
| `Positive limit triggered!` | 正限位触发 |
| `Negative limit triggered!` | 负限位触发 |
| `Unknown command: 0xXX` | 未知命令 |

---

## 6. 发送示例

使用 SSCOM、串口助手或 Python 发送时，必须选择 HEX 发送，不要附加回车换行。

| 操作 | 发送内容 |
|:---|:---|
| 正转 5 档 | `AA 01 05 B0` |
| 反转 3 档 | `AA 02 03 AF` |
| 停止 | `AA 03 00 AD` |
| 急停 | `AA 04 00 AE` |
| 调零 | `AA 05 00 AF` |

---

## 7. 版本记录

| 版本 | 日期 | 说明 |
|:---|:---|:---|
| v1.0 | 2026-07 | 初始版本，定义 4 字节控制帧与命令总表 |
```

直接把上面这一整块内容复制，粘贴到 GitHub 上新建的 `通信协议.md` 文件里就行。

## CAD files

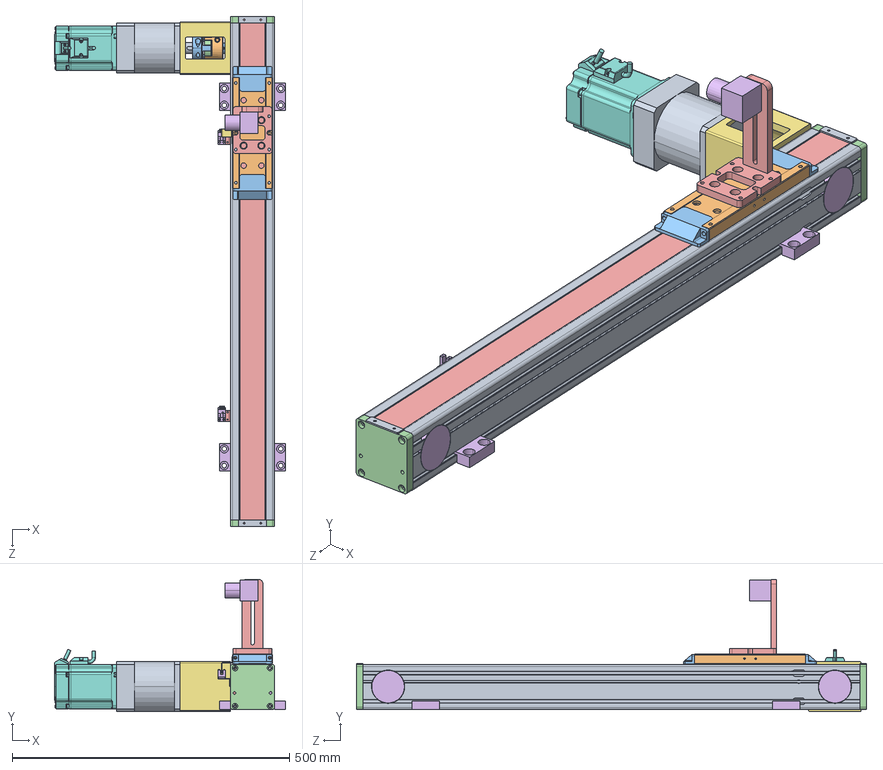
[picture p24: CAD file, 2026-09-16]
mechanical/装配体6.STEP
416.7 x 238.5 x 920.0 mm
ECB80D-L200-S500-R-750W+熬厒儂.step
L型支架^ECB80D-L200-S500-R-750W+减速机.step
眈儂

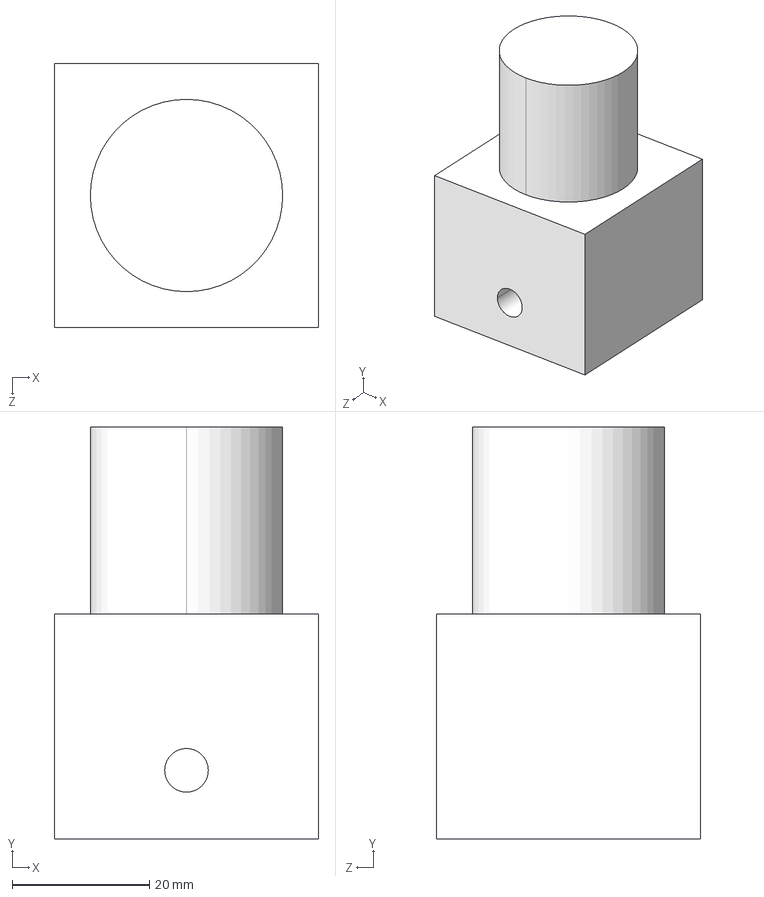
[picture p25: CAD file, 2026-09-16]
mechanical/相机.STEP
38.5 x 60.0 x 38.5 mm

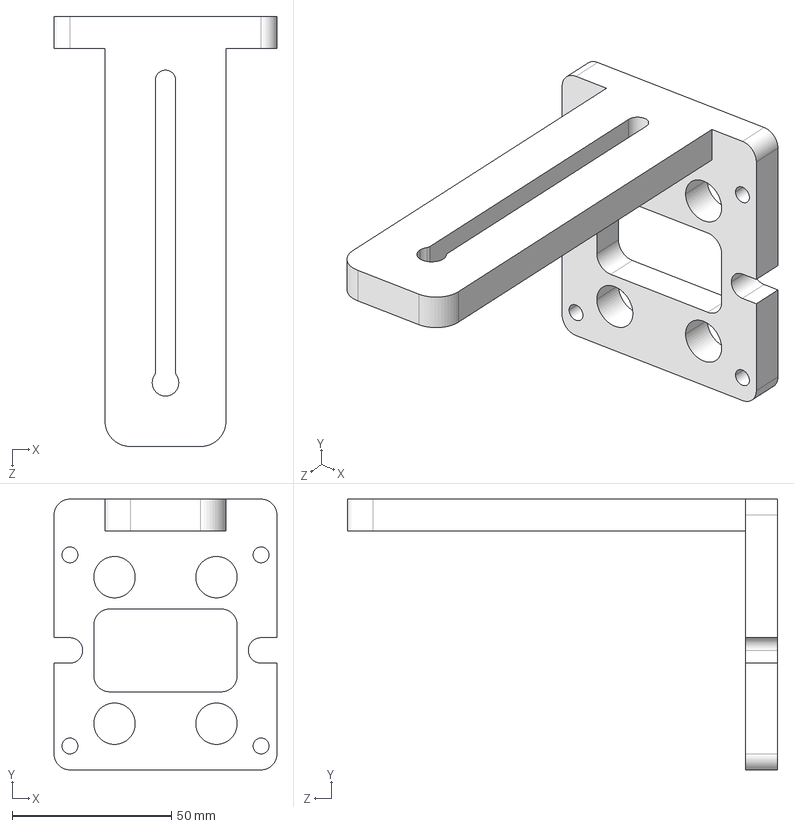
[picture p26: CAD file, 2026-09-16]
mechanical/L型支架.STEP
70.0 x 85.0 x 135.0 mm

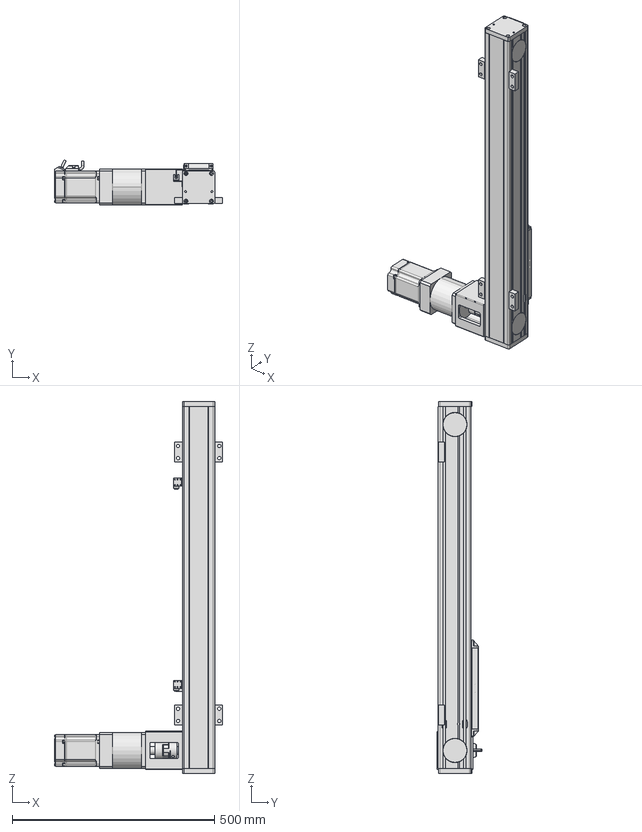
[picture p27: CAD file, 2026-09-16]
mechanical/0003-ECB80D-L200-S500-R-750W+减速机.step
416.7 x 112.5 x 920.0 mm

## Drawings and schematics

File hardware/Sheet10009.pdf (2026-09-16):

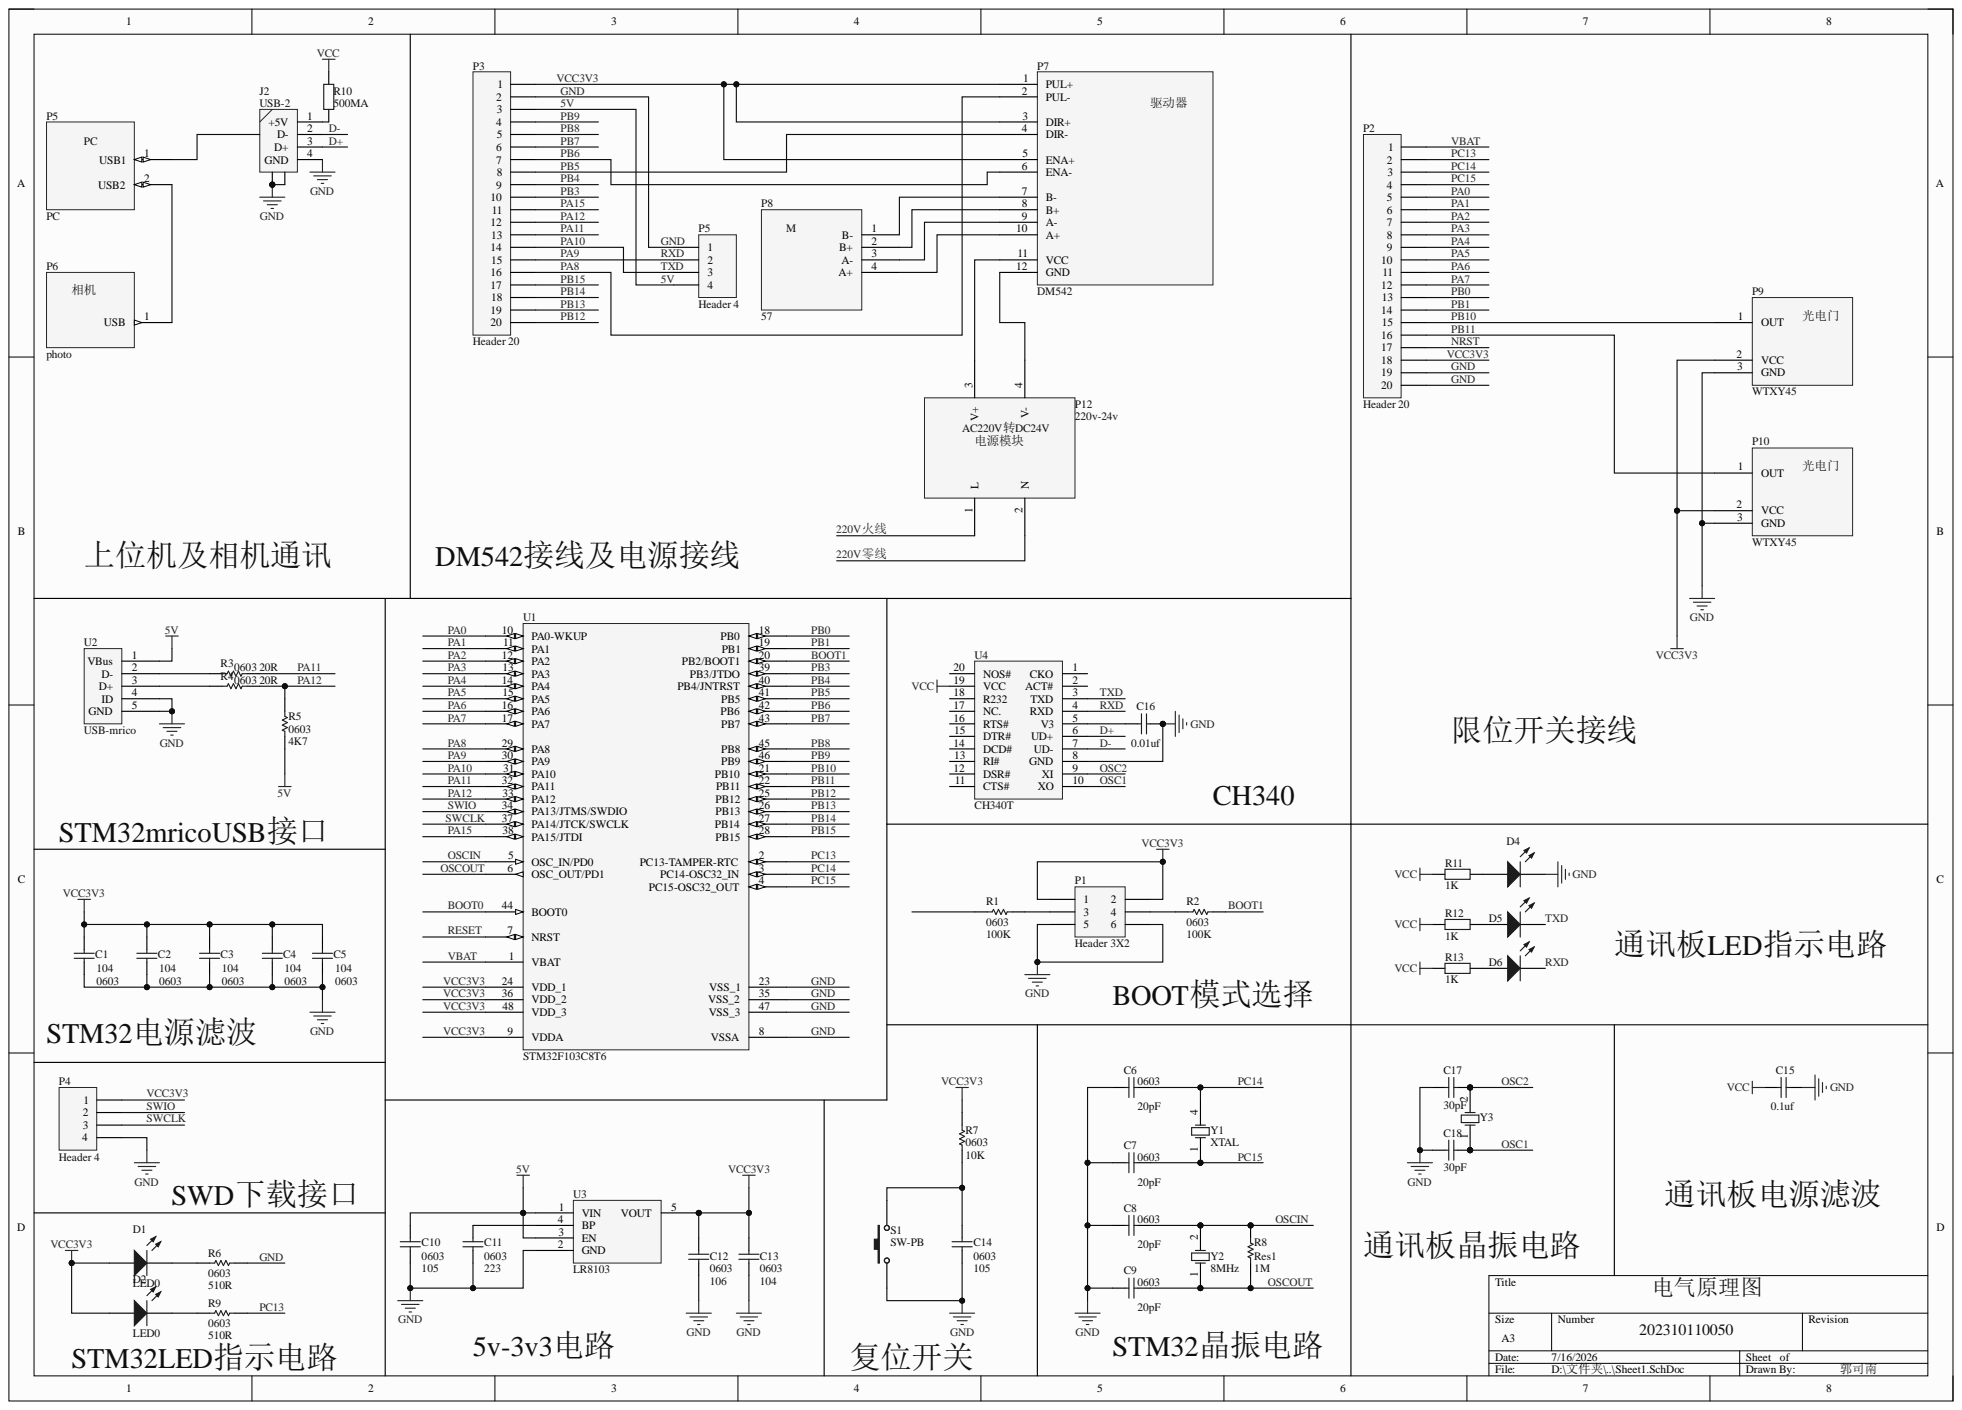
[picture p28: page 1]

PA8 TXD

VCC 2
GND 3

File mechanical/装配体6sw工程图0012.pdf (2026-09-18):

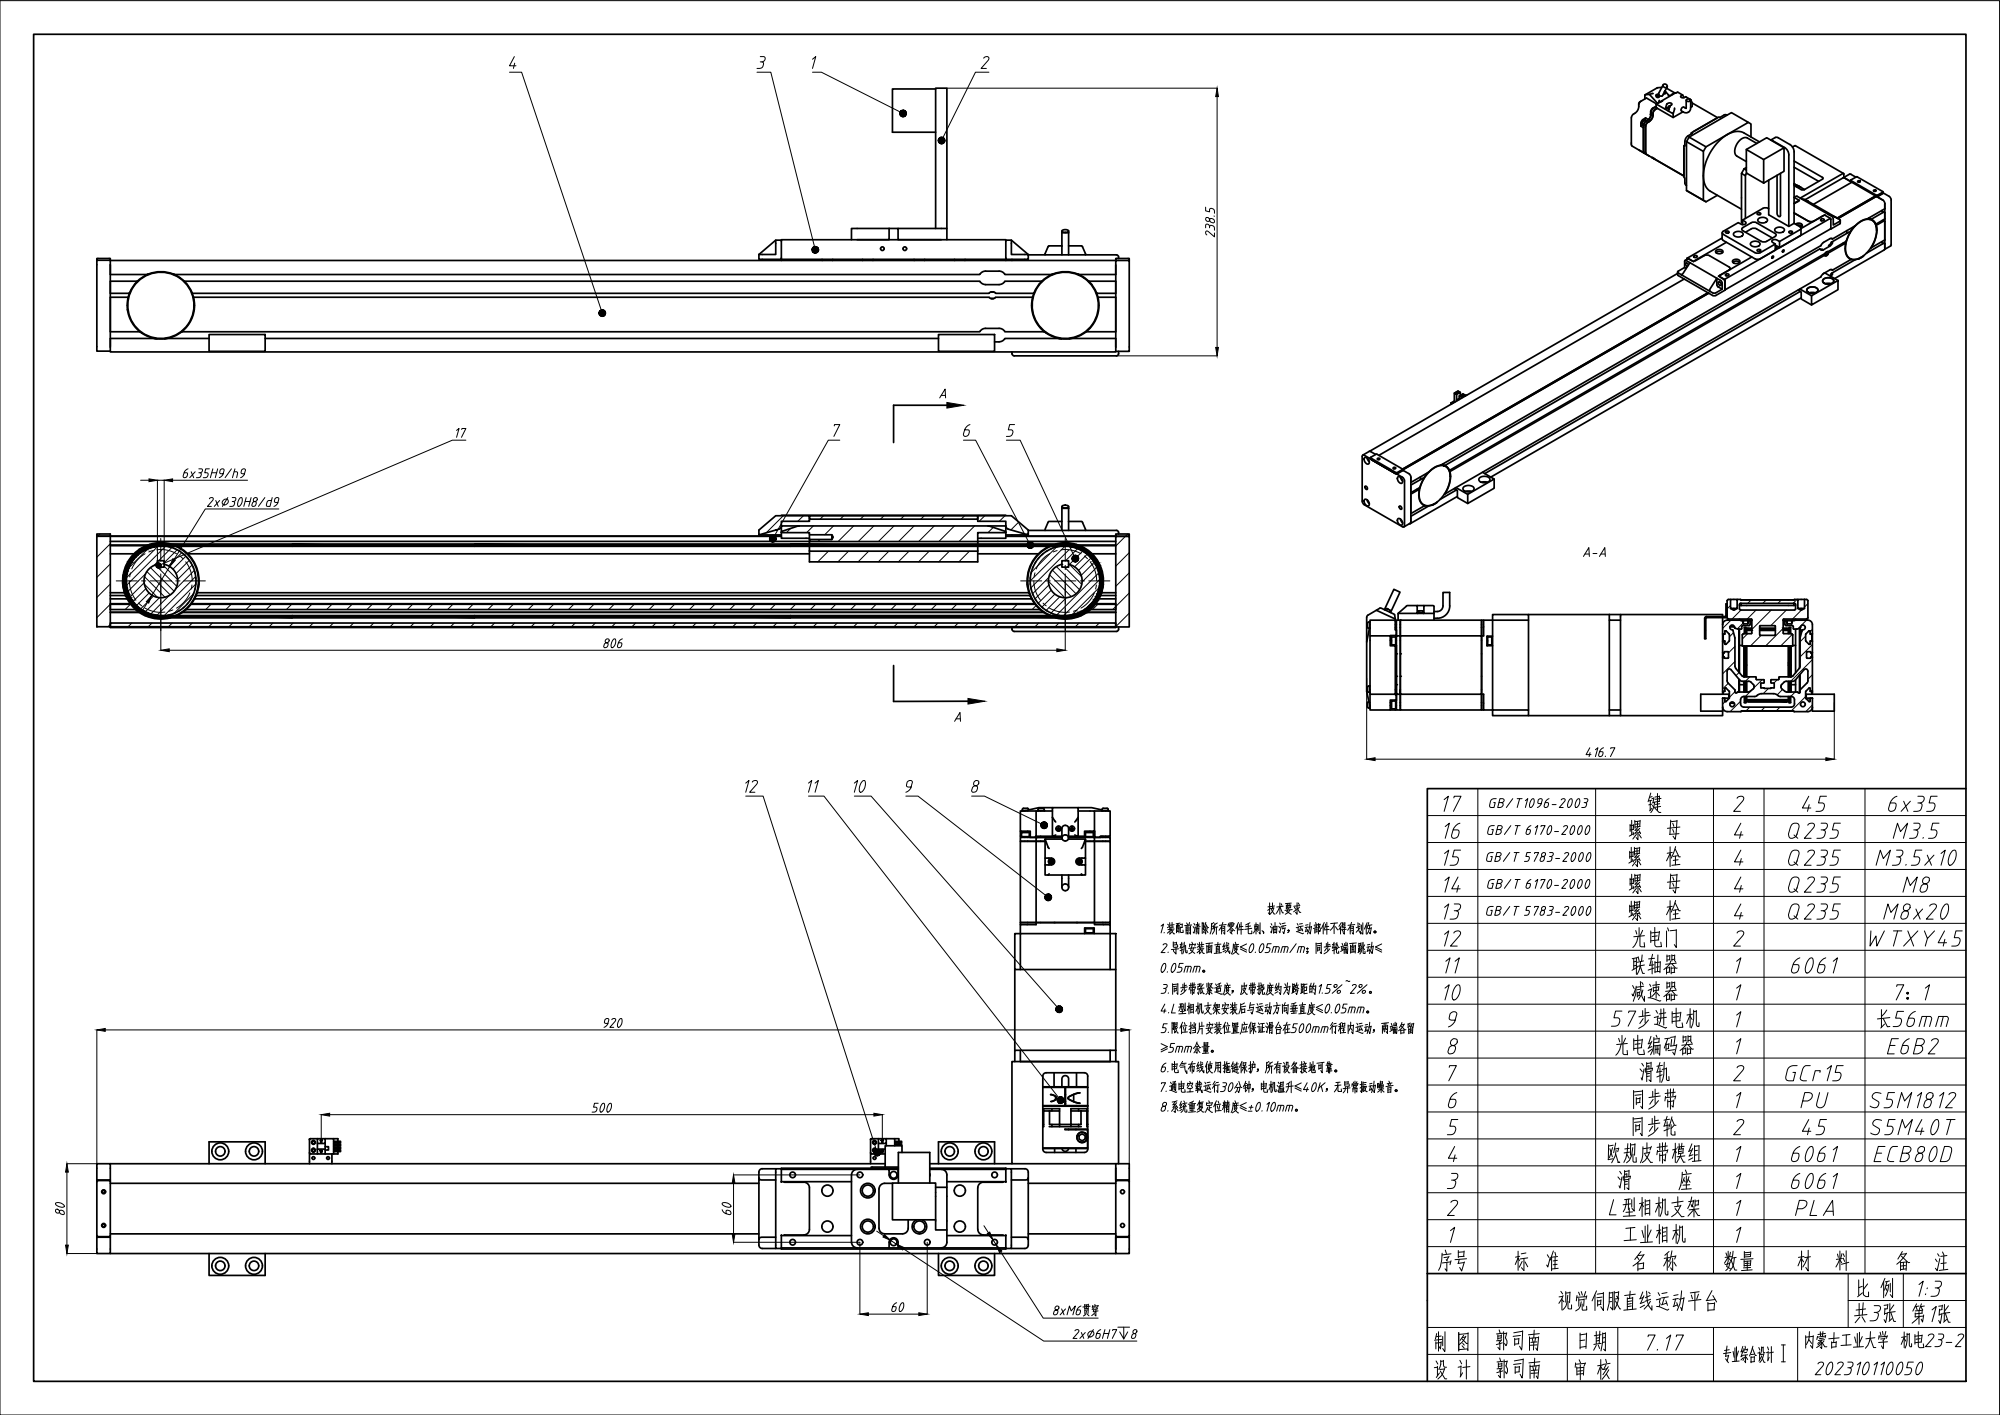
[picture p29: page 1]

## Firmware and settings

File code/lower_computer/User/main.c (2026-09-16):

#include "stm32f10x.h"
#include "Delay.h"
#include "Motor.h"
#include "Serial.h"
#include <stdio.h>

// ========== 仅在此处定义 main.c 专用的全局变量 ==========
volatile uint8_t homing_flag = 0;   // 调零进行中标志

// 定义光电门触发电平（NPN常开：触发为低电平）
#define LIMIT_TRIGGER_LEVEL   RESET

// 函数声明（本文件内部函数）
void process_command(uint8_t cmd, uint8_t data);
void check_limits(void);
void homing_process(void);

// ========== 主函数 ==========
int main(void)
{
    NVIC_PriorityGroupConfig(NVIC_PriorityGroup_2);   // 设置中断优先级分组
    
    Delay_ms(10);
    Motor_Init();
    Serial_Init();
	  
	  homing_flag = 1;
    motor_dir = 0;           // 反转找零点
    Motor_SetSpeed(3);       // 低速
    Motor_Start();
    printf("Auto homing started\r\n");
	  
    printf("\r\nSTM32 Stepper Motor Controller Ready.\r\n");
    printf("Commands: 0x01=Forward, 0x02=Reverse, 0x03=Stop, 0x04=Emergency, 0x05=Homing\r\n");
    printf("Speed level default: %d\r\n", speed_level);
    
    while (1)
    {
			uint8_t pb10 = GPIO_ReadInputDataBit(GPIOB, GPIO_Pin_10);
    uint8_t pb11 = GPIO_ReadInputDataBit(GPIOB, GPIO_Pin_11);
    printf("PB10=%d, PB11=%d\r\n", pb10, pb11);
    Delay_ms(500);  // 每500ms打印一次
			
        // 调零状态机
        if (homing_flag) {
            homing_process();
            Delay_ms(10);
            continue;
        }
        
        // 限位保护（仅在电机运行时）
        if (motor_running) {
            check_limits();
        }
        
        Delay_ms(10);
    }
		
}

// ========== 串口命令处理（由串口中断调用）==========
void process_command(uint8_t cmd, uint8_t data)
{
    switch (cmd) {
        case 0x01:  // 正转
            if (!homing_flag) {
                if (data >= 1 && data <= 10) {
                    speed_level = data;
                    Motor_SetSpeed(speed_level);
                }
                motor_dir = 1;
                Motor_Start();
                printf("Forward, speed level: %d\r\n", speed_level);
            }
            break;
        case 0x02:  // 反转
            if (!homing_flag) {
                if (data >= 1 && data <= 10) {
                    speed_level = data;
                    Motor_SetSpeed(speed_level);
                }
                motor_dir = 0;
                Motor_Start();
                printf("Reverse, speed level: %d\r\n", speed_level);
            }
            break;
        case 0x03:  // 停止
            Motor_Stop();
            printf("Stop\r\n");
            break;
        case 0x04:  // 急停
            Motor_EmergencyStop();
            printf("Emergency Stop!\r\n");
            break;
        case 0x05:  // 调零
            if (!homing_flag) {
                homing_flag = 1;
                motor_dir = 0;           // 反转寻找零点
                Motor_SetSpeed(3);       // 使用低速（35 rpm）调零
                Motor_Start();
                printf("Homing start...\r\n");
            }
            break;
        default:
            printf("Unknown command: 0x%02X\r\n", cmd);
            break;
    }
}

// ========== 限位检测 ==========
void check_limits(void)
{
    // 正转时检测正限位（PB11）
    if (motor_dir == 1) {
        if (GPIO_ReadInputDataBit(GPIOB, GPIO_Pin_11) == LIMIT_TRIGGER_LEVEL) {
            Motor_EmergencyStop();
            printf("Positive limit triggered!\r\n");
        }
    } 
    // 反转时检测负限位/零点（PB10）
    else {
        if (GPIO_ReadInputDataBit(GPIOB, GPIO_Pin_10) == LIMIT_TRIGGER_LEVEL) {
            Motor_EmergencyStop();
            printf("Negative limit triggered!\r\n");
        }
    }
}

// ========== 调零过程 ==========
void homing_process(void)
{
    // 检测零点光电门（PB10）触发
    if (GPIO_ReadInputDataBit(GPIOB, GPIO_Pin_10) == LIMIT_TRIGGER_LEVEL) {
        Motor_Stop();
        motor_position = 0;
        homing_flag = 0;
        printf("Homing complete, position = 0\r\n");
    }
    // 若在调零过程中意外触发了正限位（安全保护）
    if (GPIO_ReadInputDataBit(GPIOB, GPIO_Pin_11) == LIMIT_TRIGGER_LEVEL) {
        Motor_EmergencyStop();
        homing_flag = 0;
        printf("Homing failed: positive limit reached\r\n");
    }
}

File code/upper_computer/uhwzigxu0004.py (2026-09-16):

import cv2
import numpy as np
import serial
import serial.tools.list_ports
import time
import sys

# ==================== 配置区 ====================
CAMERA_ID = 0
BAUDRATE = 115200
SPEED_LEVEL = 3              # 手动控制默认速度档位（1~10）
AUTO_SPEED = 3               # 自动对准固定速度（强制3档，避免帧率低震荡）
DEAD_ZONE = 15               # 死区（像素）
AUTO_IDLE_TIME = 1.0         # 手动空闲多久后进入自动对准（秒）
HOMING_TIMEOUT = 10          # 调零最大等待时间（秒）

# 红色HSV阈值
LOWER_RED1 = np.array([0, 100, 100])
UPPER_RED1 = np.array([10, 255, 255])
LOWER_RED2 = np.array([160, 100, 100])
UPPER_RED2 = np.array([180, 255, 255])

# ==================== 串口功能 ====================
def find_ch340_port():
    ports = serial.tools.list_ports.comports()
    for port, desc, hwid in ports:
        if "CH340" in desc or "USB-SERIAL" in desc or "USB Serial" in desc:
            return port
    return None

def send_command(ser, cmd, data):
    if ser is None:
        return
    checksum = (0xAA + cmd + data) & 0xFF
    frame = bytes([0xAA, cmd, data, checksum])
    ser.write(frame)

def send_stop(ser):
    send_command(ser, 0x03, 0)

def send_forward(ser, speed):
    send_command(ser, 0x01, speed)

def send_reverse(ser, speed):
    send_command(ser, 0x02, speed)

def send_homing(ser):
    send_command(ser, 0x05, 0)

# ==================== 视觉识别 ====================
def detect_red_target(frame):
    hsv = cv2.cvtColor(frame, cv2.COLOR_BGR2HSV)
    mask1 = cv2.inRange(hsv, LOWER_RED1, UPPER_RED1)
    mask2 = cv2.inRange(hsv, LOWER_RED2, UPPER_RED2)
    mask = cv2.bitwise_or(mask1, mask2)
    kernel = np.ones((5, 5), np.uint8)
    mask = cv2.morphologyEx(mask, cv2.MORPH_OPEN, kernel)
    mask = cv2.morphologyEx(mask, cv2.MORPH_CLOSE, kernel)
    contours, _ = cv2.findContours(mask, cv2.RETR_EXTERNAL, cv2.CHAIN_APPROX_SIMPLE)
    if not contours:
        return None
    largest = max(contours, key=cv2.contourArea)
    if cv2.contourArea(largest) < 100:
        return None
    M = cv2.moments(largest)
    if M["m00"] == 0:
        return None
    return (int(M["m10"] / M["m00"]), int(M["m01"] / M["m00"]))

def draw_debug(frame, target, dx, mode, estop, speed):
    h, w = frame.shape[:2]
    cx = w // 2
    cv2.line(frame, (cx, 0), (cx, h), (255, 255, 255), 1)
    if target:
        tx, ty = target
        cv2.circle(frame, (tx, ty), 10, (0, 255, 0), 2)
        cv2.line(frame, (cx, ty), (tx, ty), (0, 255, 255), 1)
        cv2.putText(frame, f"dx: {dx}px", (10, 30),
                    cv2.FONT_HERSHEY_SIMPLEX, 0.7, (0, 255, 255), 2)
    else:
        cv2.putText(frame, "No target!", (10, 30),
                    cv2.FONT_HERSHEY_SIMPLEX, 0.7, (0, 0, 255), 2)
    cv2.putText(frame, f"Manual Speed: {speed}", (10, 60),
                cv2.FONT_HERSHEY_SIMPLEX, 0.6, (255, 255, 0), 1)
    cv2.putText(frame, f"Auto Speed: {AUTO_SPEED} (fixed)", (10, 85),
                cv2.FONT_HERSHEY_SIMPLEX, 0.5, (200, 200, 200), 1)
    cv2.putText(frame, f"Mode: {mode}", (10, 110),
                cv2.FONT_HERSHEY_SIMPLEX, 0.6, (200, 200, 200), 1)
    if estop:
        cv2.putText(frame, "!!! E-STOP ACTIVE !!!", (w//2-150, 50),
                    cv2.FONT_HERSHEY_SIMPLEX, 1.0, (0, 0, 255), 3)
    cv2.putText(frame, "W/S: move  Space:stop  E:emerg  Z:home  0-9:speed  Q:quit",
                (10, h-10), cv2.FONT_HERSHEY_SIMPLEX, 0.5, (150, 150, 150), 1)

# ==================== 自动对准更新（强制速度 = AUTO_SPEED） ====================
last_dir_sent = 0   # 0=停止, 1=正转, -1=反转
last_stop_sent = False

def auto_align_update(ser, cap):
    global last_dir_sent, last_stop_sent

    ret, frame = cap.read()
    if not ret:
        return False

    target = detect_red_target(frame)
    if target is None:
        if not last_stop_sent:
            send_stop(ser)
            last_dir_sent = 0
            last_stop_sent = True
        draw_debug(frame, None, 0, "AutoAlign (no target)", False, SPEED_LEVEL)
        cv2.imshow("Visual Servo", frame)
        return False

    last_stop_sent = False

    h, w = frame.shape[:2]
    cx = w // 2
    tx, ty = target
    dx = tx - cx

    draw_debug(frame, target, dx, "AutoAlign", False, SPEED_LEVEL)
    cv2.imshow("Visual Servo", frame)

    if abs(dx) < DEAD_ZONE:
        if not last_stop_sent:
            send_stop(ser)
            last_dir_sent = 0
            last_stop_sent = True
        return True

    # 未居中：决定方向，使用固定 AUTO_SPEED
    if dx > 0:
        if last_dir_sent != -1:
            send_reverse(ser, AUTO_SPEED)   # 强制用 AUTO_SPEED
            last_dir_sent = -1
            last_stop_sent = False
    else:
        if last_dir_sent != 1:
            send_forward(ser, AUTO_SPEED)   # 强制用 AUTO_SPEED
            last_dir_sent = 1
            last_stop_sent = False

    return False
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

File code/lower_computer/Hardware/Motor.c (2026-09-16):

#include "Motor.h"
#include "PWM.h"
#include <stdio.h>

// ========== 全局变量定义（只在此处定义一次）==========
volatile uint8_t motor_running = 0;
volatile uint8_t motor_dir = 1;      // 1:正转, 0:反转
volatile int32_t motor_position = 0;
volatile uint8_t speed_level = 5;

// 速度档位对应的ARR值（细分3200步/圈，TIM1频率1MHz）
// 转速范围：15~200 rpm
const uint16_t speed_arr[11] = {
    0,      // 索引0不用
    1250,   // 1档: 15 rpm
    750,    // 2档: 25 rpm
    536,    // 3档: 35 rpm
    375,    // 4档: 50 rpm
    268,    // 5档: 70 rpm
    208,    // 6档: 90 rpm
    171,    // 7档: 110 rpm
    134,    // 8档: 140 rpm
    110,    // 9档: 170 rpm
    94      // 10档: 200 rpm
};

// ========== 函数实现 ==========
void Motor_Init(void)
{
    // 开启GPIO和TIM1时钟
    RCC_APB2PeriphClockCmd(RCC_APB2Periph_GPIOA | RCC_APB2Periph_GPIOB | RCC_APB2Periph_TIM1, ENABLE);
    
    GPIO_InitTypeDef GPIO_InitStruct;
    
    // PA8 - TIM1_CH1 复用推挽
    GPIO_InitStruct.GPIO_Pin = GPIO_Pin_8;
    GPIO_InitStruct.GPIO_Mode = GPIO_Mode_AF_PP;
    GPIO_InitStruct.GPIO_Speed = GPIO_Speed_50MHz;
    GPIO_Init(GPIOA, &GPIO_InitStruct);
    
    // PB5 - 方向控制
    GPIO_InitStruct.GPIO_Pin = GPIO_Pin_5;
    GPIO_InitStruct.GPIO_Mode = GPIO_Mode_Out_PP;
    GPIO_InitStruct.GPIO_Speed = GPIO_Speed_50MHz;
    GPIO_Init(GPIOB, &GPIO_InitStruct);
    GPIO_ResetBits(GPIOB, GPIO_Pin_5);   // 默认正转（假设低电平正转）
    
    // PB10, PB11 - 光电门输入（上拉）
    GPIO_InitStruct.GPIO_Pin = GPIO_Pin_10 | GPIO_Pin_11;
    GPIO_InitStruct.GPIO_Mode = GPIO_Mode_IPU;
    GPIO_Init(GPIOB, &GPIO_InitStruct);
    
    // 初始化PWM
    PWM_Init();
    
    // 设置默认速度
    Motor_SetSpeed(speed_level);
}

void Motor_SetSpeed(uint8_t level)
{
    if (level < 1) level = 1;
    if (level > 10) level = 10;
    speed_level = level;
    uint16_t arr = speed_arr[level];
    PWM_SetFrequency(arr);
}

void Motor_Start(void)
{
    // 设置方向
    if (motor_dir == 1) {
        GPIO_ResetBits(GPIOB, GPIO_Pin_5);   // 低电平正转（根据实际调整）
    } else {
        GPIO_SetBits(GPIOB, GPIO_Pin_5);
    }
		
    PWM_Start();
    motor_running = 1;
}

void Motor_Stop(void)
{
    PWM_Stop();
    motor_running = 0;
    // 不操作EN，DM542默认使能，保持锁死（刹车）
}

void Motor_EmergencyStop(void)
{
    PWM_Stop();
    motor_running = 0;
	printf("Motor_Stop called, PWM should be stopped\r\n");
}

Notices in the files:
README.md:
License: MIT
